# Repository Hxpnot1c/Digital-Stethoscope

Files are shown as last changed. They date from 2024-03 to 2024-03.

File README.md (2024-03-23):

# Digital-Stethoscope

## Video Presentation

Presentation video by Calday Robotics (https://www.youtube.com/watch?v=tSeS5dvHLK4)

## Video Demonstration

Demonstration video by Calday Robotics (https://www.youtube.com/watch?v=pRtG8VmfHiQ)

## Summary
<details>
    <summary>500 Word Summary</summary>
<br />
In regions where access to advanced medical equipment is limited, diagnosing cardiac irregularities such as arrhythmias, murmurs and extrasystoles poses significant challenges for healthcare providers. Our solution; a 3D printed, digital stethoscope with integrated AI. 

While analogue stethoscopes are still a vital and valued tool, it poses issues that need to be addressed. Namely, the heartbeat can be quiet, making it difficult for doctors to accurately diagnose. Moreover, they lack visual representation, which could enhance understanding.

Our device tackles these challenges with advanced sound capture. It amplifies heartbeats using a 3D printed stethoscope head, then records them with a microphone. This captured sound data is processed in real-time to create a live graph of the patient's heartbeat and rhythm. The device features a user-friendly interface that displays this live plot alongside fields for recording patient information and notes.

What sets it apart is its integration with advanced artificial intelligence, enabling discrete real-time analysis of recorded data. The integrated AI uses a deep convolutional neural network to diagnose heart irregularities such as murmurs and extrasystoles. First, the audio data is converted into features such as the zero crossing rate, a chroma short time Fourier transform, the Mel-frequency cepstrum coefficient and a Mel-Spectrogram. This allows for unnecessary information to be abstracted from the input data. The data is then fed into a deep neural network that consists of 5 layers and over 95,000 trainable parameters. This network consists of 3, 1-Dimensional convolutional layers and 2 Linear Layers. In order to train the model, we used a cross-entropy loss function and the AdamW optimiser. In order to prevent overfitting, we set the AdamW optimiser with an aggressive weight decay, upsampled minority classes and created synthetic data with added noise. This allowed it to achieve an accuracy of 98% on data that it had never seen before.

Healthcare providers will be able to receive immediate feedback and diagnostic suggestions, empowering them to make prompt and informed decisions regarding patient care.

One of the main benefits of this digital stethoscope is its low cost. With a total cost of only £40.94. Compared to traditional stethoscopes, our stethoscope presents itself as a key-choice in resource-constrained settings. In order to achieve this, we used a Raspberry Pi 3 Model B+ due to its sufficient processing power while minimising costs and an FDM 3D printer to create a majority of the stethoscope. The head and ring are made out of PLA and the connection piece for the microphone is made out of TPU to provide a sound isolating fit for the microphone. The cost allows for our design to be much more accessible in areas where medical resources are limited.

By facilitating early detection of cardiac irregularities, the Digital Stethoscope enables timely intervention and improved patient outcomes. Its accessibility extends to underserved communities, where access to specialised equipment is limited. With its potential to revolutionise cardiac diagnostics in developing countries, the Digital Stethoscope holds promise for saving lives and improving healthcare delivery worldwide.
</details>
 
## Build Guide
<details>
    <summary>Build guide</summary>
<br />
    
Print all 3D models in 'Digital-Stethoscope/3d_models':<br />
-  PLA_Stethoscope_Head.stl should be printed in PLA with 100% infil
-  PLA_Stethoscope_Ring.stl should be printed in PLA with 100% infill
-  TPU_Stethoscope_Connection.stl should be printed in TPU with 100% infill

Note: Our models were printed using a Creality CR10 Smart Pro 3D printer. Most FDM 3D printers will be sufficient.<br />

We also used the default setting on Cura slicer (with 100% infill).<br />
For Stethoscope Ring: Supports ON - Normal<br />

For the diaphragm, we used a 40mm diameter silicone piece with a thickness of 0.35mm

See Assembly Video below for a 3D rendering of how to assemble the 3D printed parts and the diaphragm.

Substitutionary Rick Roll to be replaced with assembly video (https://www.youtube.com/watch?v=KgJvibv4-vc)

All connections require no adhesive and rely on a friction fit.
In order to attach the Ring some pressure will be required, this will then provide a tight fit.

The microphone will then also provide a tight fit into the TPU connection piece

The following connections may require soldering and the use of breadboards. Please see the below pinout images to demonstrate pin connections.<br />
Connect V<sub>DD</sub> on the MCP3008 ADC to 3.3V on the Raspberry Pi using pin 17<br />
Connect V<sub>REF</sub> on the MCP3008 ADC to 3.3V on the Raspberry Pi using pin 17<br />
Connect AGND on the MCP3008 ADC to GND on the Raspberry Pi using pin 25<br />
Connect CLK on the MCP3008 ADC to GPIO 11 (SCLK) on the Raspberry Pi using pin 23<br />
Connect D<sub>OUT</sub> on the MCP3008 ADC to GPIO 9 (MISO) on the Raspberry Pi using pin 21<br />
Connect D<sub>IN</sub> on the MCP3008 ADC to GPIO 10 (MOSI) on the Raspberry Pi using pin 19<br />
Connect CS/SHDN on the MCP3008 ADC to GPIO 8 (CE0) on the Raspberry Pi using pin 8<br />
Connect GND on the MAX9814 microphone to GND on the Raspberry Pi using pin 25<br />
Connect V+ on the MAX9814 microphone to 3.3V on the Raspberry Pi using pin 17<br />
Connect OUT on the MAX9814 microphone to CH0 on the MCP3008 ADC<br />

Raspberry Pi pinout
MCP3008 ADC pinout
MAX9814 microphone pinout

The Raspberry Pi should be setup with Raspberry Pi OS (Legacy, 64 bit)<br />
Note: 64 bit is required for pytorch

Install the following dependencies using pip:<br />
-  adafruit_mcp3008
-  librosa
-  matplotlib
-  pandas
-  pyqt5
-  soundfile
-  torch

Download 'Digital-Stethoscope/src'

Run the following commands in the terminal to run the program:<br />
'sudo chrt 99 python src/model_prediction.py'
'sudo chrt 99 python src/gui.py'
'sudo chrt 99 python src/data_acquisition.py'
</details>

## Further Reading
<details>
    <summary>Definitions and useful links</summary>
<br />
Definitions:
Heart Arrhythmia:<br />
An arrhythmia is an abnormality of the heart's rhythm.

Heart Murmur:<br />
Heart murmurs are sounds — such as whooshing or swishing — made by rapid, choppy (turbulent) blood flow through the heart.

Extrasystoles/Premature ventricular contractions:<br />
Extra heartbeats that begin in one of the heart's two lower pumping chambers (ventricles).

Zero-Crossing Rate (ZCR):<br />
A measurement in audio processing that counts the number of times a signal crosses zero from positive to negative or vice versa within a specific time window. It's a simple way to characterise the "brightness" or "harshness" of a sound.
    
Chroma Short-Time Fourier Transform (Chroma STFT):<br />
A signal processing technique used to analyse audio. It breaks down the sound into its component frequencies over short periods of time. Chroma STFT focuses specifically on the pitch information, representing the signal in terms of musical notes (chroma).
    
Mel-Frequency Cepstrum Coefficient (MFCC):<br />
A feature extraction technique commonly used in speech and audio recognition. It mimics how the human auditory system perceives sound by converting the sound's frequency spectrum into a representation on the Mel scale, which approximates human hearing. MFCCs capture the spectral envelope of the sound, making them useful for tasks like speaker identification and speech recognition.
    
Mel-Spectrogram:<br />
A visual representation of a sound's frequency content over time. It uses colour to represent the intensity of different frequencies at different time points. Mel spectrograms are often used in conjunction with MFCCs, as they provide a more intuitive way to understand the spectral information captured by MFCCs.
    
Deep Neural Network (DNN):<br />
A type of artificial neural network with multiple layers of interconnected nodes. DNNs can learn complex patterns from data and are powerful tools for tasks like image recognition, natural language processing, and speech recognition.
    
Convolutional Neural Network (CNN):<br />
A powerful type of artificial neural network used to classify sounds. Similar to image processing, CNNs excel at finding patterns in audio data.
    
Trainable Parameters:<br />
The numerical values within a deep neural network that are adjusted during the training process. These parameters determine how the network maps input data to output predictions. By adjusting these parameters, the network learns to perform a specific task.
    
1-Dimensional Convolutional Layers:<br />
A specific type of layer in a deep neural network used for processing sequential data like audio or text. These layers apply a filter (like a small window) that slides across the input data, extracting features based on local patterns. By stacking multiple convolutional layers, the network can learn increasingly complex features.
    
Linear Layers:<br />
Layers in a deep neural network that perform a weighted sum of their inputs. These layers are often used at the end of a network to combine the learned features and produce the final output prediction.
    
ReLU Activation Function:<br />
A popular activation function used in artificial neural networks. It adds a non-linearity to the network, which is crucial for its ability to learn complex patterns from data.
    
Cross-Entropy Loss Function:<br />
A common function used to measure the error between a neural network's predictions and the true labels of the data. It's particularly useful for classification tasks where the network outputs probabilities for different categories. The loss function helps the network learn by indicating how much its predictions deviate from the desired outcome.
    
AdamW Optimizer:<br />
An optimization algorithm used to train deep neural networks. It efficiently adjusts the network's trainable parameters based on the calculated loss function. AdamW is a variant of the Adam optimizer that addresses certain stability issues.
    
Overfitting:<br />
A situation where a deep neural network performs well on the training data but poorly on unseen data. This occurs when the network memorises specific details of the training examples rather than learning generalisable patterns. Weight decay and other regularisation techniques can help prevent overfitting.
    
Weight Decay:<br />
A technique used during training to prevent a deep neural network from overfitting to the training data. It penalises the network for having large weights, encouraging it to learn more generalisable features.
    
Dropout Layers:<br />
A technique used in artificial neural networks to improve their performance, especially to address overfitting, by randomly deactivating a certain percentage of neurons in a layer during training. This forces the network to learn to use different combinations of neurons each time, preventing it from relying too heavily on any specific neuron or connection.
    
Upsampling:<br />
An operation that increases the resolution of an image or signal. In audio processing, it might involve interpolating new data points between existing ones to create a higher sampling rate.
    
Minority Classes:<br />
In a classification task with multiple categories, the classes with the fewest data points are referred to as minority classes.
    
Class Imbalance:<br />
A situation in a classification dataset where some classes have significantly fewer data points than others. This can pose challenges for training a deep neural network, as the model might prioritise learning patterns from the majority classes and perform poorly on the minority classes.
    
Noise (in reference to audio):<br />
Unwanted sound that disrupts the desired audio signal. Noise can come from various sources and can significantly impact the quality and clarity of audio recordings or playback.
    
MAX9814:<br />
An integrated circuit (IC) that combines a microphone amplifier with automatic gain control (AGC). It's commonly used in audio applications to boost weak microphone signals to a usable level. AGC helps ensure the amplified signal stays within a certain range, preventing distortion.
    
MCP3008:<br />
An analogue-to-digital converter (ADC) IC that converts analogue voltage signals from sensors or other circuits into digital data that can be processed by microcontrollers or computers. It has 8 channels, meaning it can convert signals from up to 8 analogue inputs simultaneously. The MCP3008 typically uses a serial communication protocol (SPI) to communicate with the microcontroller.

Links to helpful videos:
But what is a neural network? | Chapter 1, Deep learning by 3Blue1Brown<br />
But what is a convolution? by 3Blue1Brown<br />
But what is the Fourier Transform?  A visual introduction. by 3Blue1Brown<br />

</details>

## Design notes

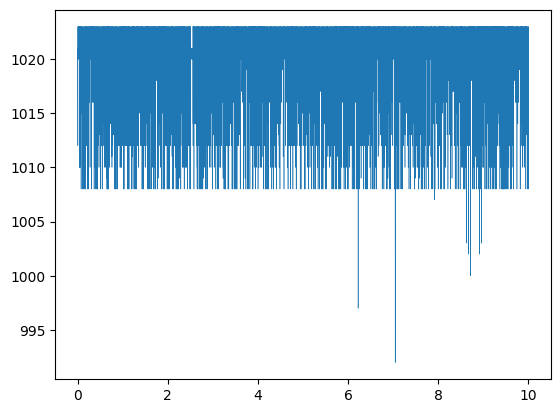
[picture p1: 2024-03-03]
Res/ADC_Readings.png

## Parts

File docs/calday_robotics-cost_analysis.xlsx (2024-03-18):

 | Name | Commercial Cost | Links
Raspberry Pi | 3 Model B+ | £39.34 | https://www.rapidonline.com/raspberry-pi-3-model-b-1-quad-core-1-4ghz-1gb-ram-wifi-bluetooth-75-1005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
PLA | Geeetech 10kg | £0.26 | https://www.aliexpress.com/item/1005006593506584.html
TPU | OVERTURE TPU Filament (1kg Spools) | £0.04 | https://www.amazon.co.uk/OVERTURE-Filament-Flexible-Consumables-Dimensional/dp/B09QLT436P
Mic | MAX9418 | £0.40 | https://www.aliexpress.com/item/1005006371216670.html
Diaphram | Jan-huei K.H. Industry Co | £0.19 | Quote from Jan-huei K.H. Industry Co., Ltd.
Wires | 2m with insulation | £0.15 | https://www.aliexpress.com/item/1005006537337468.html
ADC | MCP3008 | £0.38 | https://www.aliexpress.com/item/1005005944889779.html
Breadboard | 170 Tie Point Solderless PCB | £0.18 | https://pl.aliexpress.com/item/1005006590495350.html
Total (excluding RPi) |  | £1.60
Total |  | £40.94
 |  |  |  | $0.24 = £0.19

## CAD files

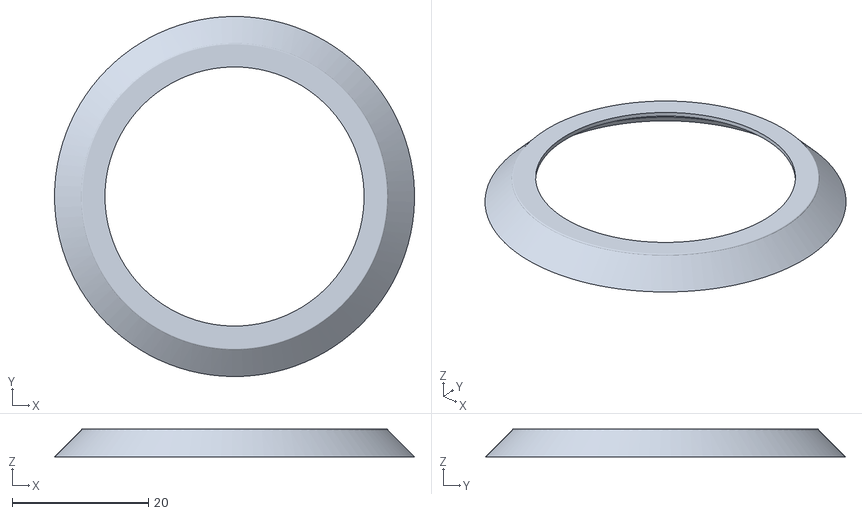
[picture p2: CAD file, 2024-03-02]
3d_models/PLA_Stethoscope_Ring.stl
52.8 x 52.8 x 4.10

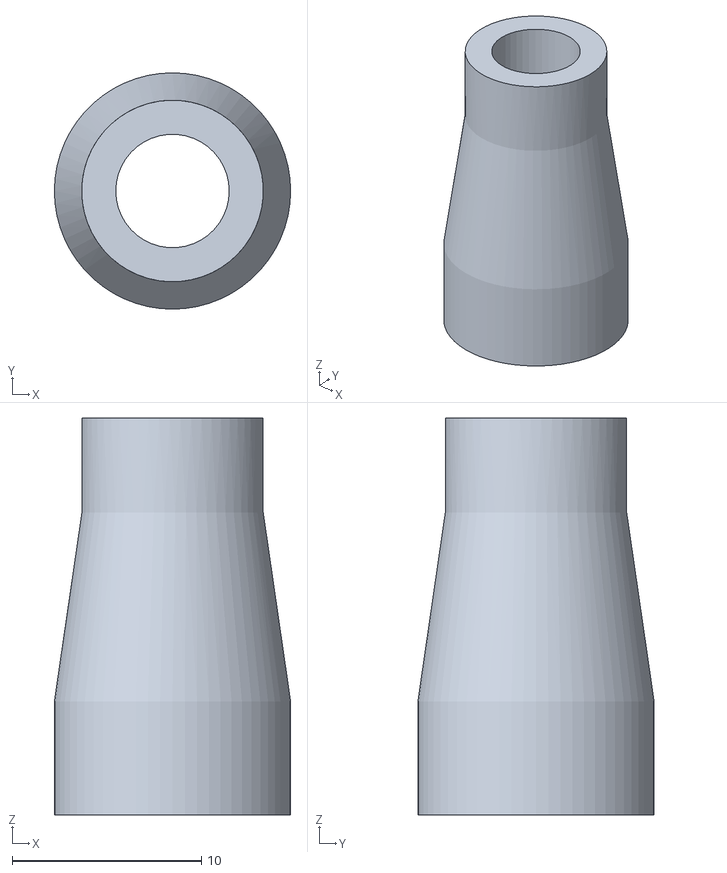
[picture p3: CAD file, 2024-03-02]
3d_models/TPU_Stethoscope_Connection.stl
12.5 x 12.5 x 21.0

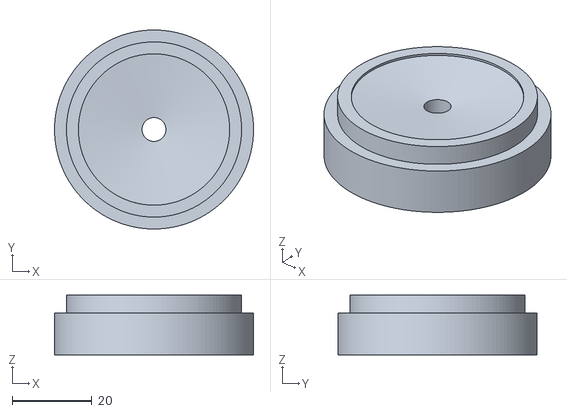
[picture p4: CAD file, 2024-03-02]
3d_models/PLA_Stethoscope_Head.stl
50.0 x 50.0 x 15.0

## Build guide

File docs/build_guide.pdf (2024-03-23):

# Build Guide

Link to GitHub - https://github.com/Hxpnot1c/Digital-Stethoscope

Print all 3D models in 'Digital-Stethoscope/3d_models':

- PLA_Stethoscope_Head.stl should be printed in PLA with 100% infill
- PLA_Stethoscope_Ring.stl should be printed in PLA with 100% infill
- TPU_Stethoscope_Connection.stl should be printed in TPU with 100% infill

Note: Our models were printed using a Creality CR10 Smart Pro 3D printer. Most FDM 3D printers will be sufficient.

We also used the default setting on Cura slicer (with 100% infill).
For Stethoscope Ring: Supports ON - Normal

For the diaphragm, we used a 40mm diameter silicone piece with a thickness of 0.35mm

See Assembly Video (https://www.youtube.com/watch?v=KgJvibv4-vc) below for a 3D rendering of how to assemble the 3D printed parts and the diaphragm.

All connections require no adhesive and rely on a friction fit. In order to attach the Ring some pressure will be required, this will then provide a tight fit.

The microphone will then also provide a tight fit into the TPU connection piece

The following connections may require soldering and the use of breadboards. Please see the below pinout images to demonstrate pin connections.
Connect VDD on the MCP3008 ADC to 3.3V on the Raspberry Pi using pin 17
Connect VREF on the MCP3008 ADC to 3.3V on the Raspberry Pi using pin 17
Connect AGND on the MCP3008 ADC to GND on the Raspberry Pi using pin 25 Connect CLK on the MCP3008 ADC to GPIO 11 (SCLK) on the Raspberry Pi using pin 23 Connect DOUT on the MCP3008 ADC to GPIO 9 (MISO) on the Raspberry Pi using pin 21 Connect DIN on the MCP3008 ADC to GPIO 10 (MOSI) on the Raspberry Pi using pin 19 Connect CS/SHDN on the MCP3008 ADC to GPIO 8 (CE0) on the Raspberry Pi using pin 8 Connect GND on the MAX9814 microphone to GND on the Raspberry Pi using pin 25 Connect V+ on the MAX9814 microphone to 3.3V on the Raspberry Pi using pin 17 Connect OUT on the MAX9814 microphone to CH0 on the MCP3008 ADC

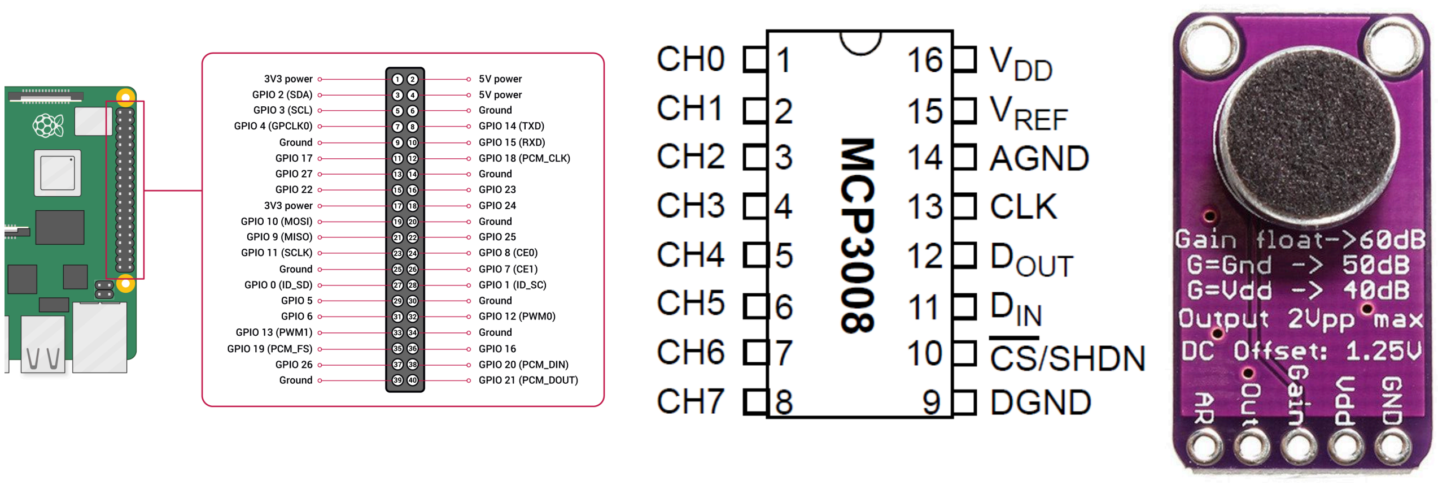
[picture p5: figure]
Note: 64 bit is required for pytorch

The Raspberry Pi should be setup with Raspberry Pi OS (Legacy, 64 bit)

Install the following dependencies using pip:

- adafruit_mcp3008
- librosa
- matplotlib
- pandas
- pyqt5
- sound file
- torch

Download 'Digital-Stethoscope/src'

Run the following commands in the terminal to run the program:

- 'sudo chrt 99 python src/model_prediction.py'
- 'sudo chrt 99 python src/gui.py'
- 'sudo chrt 99 python src/data_acquisition.py'

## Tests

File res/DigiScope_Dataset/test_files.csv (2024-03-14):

unlabelled_test/101_1305030823364_A.wav
unlabelled_test/101_1305030823364_D.wav
unlabelled_test/101_1305030823364_F.wav
unlabelled_test/103_1305031931979_A.wav
unlabelled_test/103_1305031931979_C.wav
unlabelled_test/105_1305033453095_B.wav
unlabelled_test/105_1305033453095_D.wav
unlabelled_test/106_1306776721273_B.wav
unlabelled_test/106_1306776721273_D.wav
unlabelled_test/107_1305654946865_B.wav
unlabelled_test/107_1305654946865_D.wav
unlabelled_test/108_1305654420093_C.wav
unlabelled_test/109_1305653646620_B.wav
unlabelled_test/109_1305653646620_D.wav
unlabelled_test/109_1305653972028_B.wav
unlabelled_test/109_1305653972028_D.wav
unlabelled_test/110_1305655332337_D.wav
unlabelled_test/112_1306243000964_C.wav
unlabelled_test/113_1306244002866_C.wav
unlabelled_test/115_1306259437619_D.wav
unlabelled_test/116_1306258689913_B.wav
unlabelled_test/117_1306262456650_B1.wav
unlabelled_test/118_1306262335509_A.wav
unlabelled_test/118_1306262335509_A1.wav
unlabelled_test/118_1306262335509_C2.wav
unlabelled_test/121_1306263877235_B.wav
unlabelled_test/122_1306325762831_A.wav
unlabelled_test/122_1306325762831_B.wav
unlabelled_test/123_1306331925797_A.wav
unlabelled_test/123_1306331925797_D.wav
unlabelled_test/125_1306332456645_B2.wav
unlabelled_test/126_1306777102824_C1.wav
unlabelled_test/126_1306777102824_D1.wav
unlabelled_test/127_1306764300147_D.wav
unlabelled_test/128_1306344005749_C.wav
unlabelled_test/129_1306344506305_B.wav
unlabelled_test/130_1306347376079_A.wav
unlabelled_test/132_1306758754432_A.wav
unlabelled_test/132_1306758754432_B.wav
unlabelled_test/132_1306758754432_D.wav
unlabelled_test/134_1306428161797_A.wav
unlabelled_test/134_1306428161797_B.wav
unlabelled_test/135_1306428972976_D.wav
unlabelled_test/136_1306429977501_A.wav
unlabelled_test/136_1306429977501_D.wav
unlabelled_test/137_1306764999211_A.wav
unlabelled_test/137_1306764999211_B1.wav
unlabelled_test/137_1306764999211_D2.wav
unlabelled_test/138_1306762146980_C.wav
unlabelled_test/139_1306519274653_B.wav
unlabelled_test/139_1306519274653_C.wav
unlabelled_test/141_1306520154450_A.wav
unlabelled_test/141_1306520154450_D.wav
unlabelled_test/142_1306763049574_C.wav
unlabelled_test/143_1306763822290_D.wav
unlabelled_test/144_1306522408528_A.wav
unlabelled_test/145_1307987561278_A.wav
unlabelled_test/145_1307987561278_D.wav
unlabelled_test/146_1306778707532_C.wav
unlabelled_test/146_1306778707532_D31.wav
unlabelled_test/147_1306523973811_D.wav
unlabelled_test/148_1306768801551_A.wav
unlabelled_test/148_1306768801551_C.wav
unlabelled_test/148_1306768801551_D.wav
unlabelled_test/149_1306776016110_C.wav
unlabelled_test/150_1306776340746_D.wav
unlabelled_test/151_1306779785624_A1.wav
unlabelled_test/152_1306779561195_B.wav
unlabelled_test/152_1306779561195_C.wav
unlabelled_test/152_1306779561195_D1.wav
unlabelled_test/153_1306848820671_D.wav
unlabelled_test/154_1306935608852_A.wav
unlabelled_test/154_1306935608852_A2.wav
unlabelled_test/154_1306935608852_D.wav
unlabelled_test/154_1306935608852_D1.wav
unlabelled_test/155_1306935902813_B.wav
unlabelled_test/155_1306935902813_B2.wav
unlabelled_test/155_1306935902813_D.wav
unlabelled_test/156_1306936373241_C.wav
unlabelled_test/156_1306936373241_D.wav
unlabelled_test/157_1306937583792_C.wav
unlabelled_test/159_1307018640315_A.wav
unlabelled_test/159_1307018640315_B.wav
unlabelled_test/159_1307018640315_C.wav
unlabelled_test/160_1307100683334_C.wav
unlabelled_test/161_1307101199321_D.wav
unlabelled_test/162_1307101835989_C.wav
unlabelled_test/163_1307104470471_B.wav
unlabelled_test/163_1307104470471_B1.wav
unlabelled_test/163_1307104470471_D.wav
unlabelled_test/164_1307106095995_D.wav
unlabelled_test/165_1307109069581_B.wav
unlabelled_test/167_1307111318050_C1.wav
unlabelled_test/167_1307111318050_D.wav
unlabelled_test/169_1307970398039_B.wav
unlabelled_test/169_1307970398039_C1.wav
unlabelled_test/170_1307970562729_D.wav
unlabelled_test/171_1307971016233_C.wav
unlabelled_test/171_1307971016233_F.wav
unlabelled_test/172_1307971284351_C.wav
unlabelled_test/172_1307971284351_D.wav
unlabelled_test/173_1307973611151_D.wav
unlabelled_test/174_1307987737137_C.wav
unlabelled_test/175_1307987962616_C.wav
unlabelled_test/176_1307988171173_A1.wav
unlabelled_test/176_1307988171173_C.wav
unlabelled_test/176_1307988171173_C1.wav
unlabelled_test/177_1307989650056_C.wav
unlabelled_test/178_1307989887769_A.wav
unlabelled_test/179_1307990076841_D1.wav
unlabelled_test/180_1307990956284_B.wav
unlabelled_test/180_1307990956284_D.wav
unlabelled_test/181_1308052613891_C.wav
unlabelled_test/184_1308073010307_C.wav
unlabelled_test/186_1308073648738_C.wav
unlabelled_test/186_1308073648738_D1.wav
unlabelled_test/187_1308073994223_C.wav
unlabelled_test/189_1308075231945_A.wav
unlabelled_test/189_1308075231945_C.wav
unlabelled_test/191_1308077299430_C.wav
unlabelled_test/191_1308077299430_D.wav
unlabelled_test/193_1308078104592_A.wav
unlabelled_test/193_1308078104592_D.wav
unlabelled_test/194_1308139824187_C.wav
unlabelled_test/195_1308140095331_D.wav
unlabelled_test/196_1308141034858_D.wav
unlabelled_test/197_1308141235553_B.wav
unlabelled_test/200_1308144251434_C1.wav
unlabelled_test/201_1308144942432_B.wav
unlabelled_test/202_1308145175747_B.wav
unlabelled_test/203_1308162026258_C.wav
unlabelled_test/204_1308159229275_B1.wav
unlabelled_test/206_1308159601959_C1.wav
unlabelled_test/207_1308159792607_B3.wav
unlabelled_test/209_1308162216750_B.wav
unlabelled_test/209_1308162216750_C.wav
unlabelled_test/210_1308162935880_D.wav
unlabelled_test/212_1308245076477_C.wav
unlabelled_test/213_1308245263936_B.wav
unlabelled_test/214_1308245489717_A1.wav
unlabelled_test/215_1308245664733_D.wav
unlabelled_test/216_1308245839516_B1.wav
unlabelled_test/217_1308246111629_A.wav
unlabelled_test/217_1308246111629_B.wav
unlabelled_test/217_1308246111629_D.wav
unlabelled_test/220_1308250132896_A.wav
unlabelled_test/222_1308336218979_B.wav
unlabelled_test/227_1308594233667_D.wav
unlabelled_test/229_1308594979317_C.wav
unlabelled_test/231_1308748318393_B.wav
unlabelled_test/231_1308748318393_C.wav
unlabelled_test/232_1308748524018_A1.wav
unlabelled_test/232_1308748524018_D.wav
unlabelled_test/235_1308749032454_C1.wav
unlabelled_test/235_1308749032454_D1.wav
unlabelled_test/237_1308750231222_C1.wav
unlabelled_test/239_1309195730333_D.wav
unlabelled_test/240_1309196119795_D.wav
unlabelled_test/242_1309197394064_A.wav
unlabelled_test/242_1309197394064_C.wav
unlabelled_test/243_1309197760898_D.wav
unlabelled_test/245_1309198844065_A.wav
unlabelled_test/245_1309200438094_C.wav
unlabelled_test/248_1309201683806_B.wav
unlabelled_test/248_1309201683806_D.wav
unlabelled_test/254_1309350589009_B.wav
unlabelled_test/255_1309351210897_B.wav
unlabelled_test/259_1309352630271_B.wav
unlabelled_test/260_1309353164458_A.wav
unlabelled_test/262_1309355283807_B.wav
unlabelled_test/264_1309356143724_A.wav
unlabelled_test/268_1309368960960_A.wav
unlabelled_test/268_1309368960960_E.wav
unlabelled_test/270_1309369533040_D.wav
unlabelled_test/271_1309369876160_B.wav
unlabelled_test/272_1309370164386_B.wav
unlabelled_test/274_1311075637574_C.wav
unlabelled_test/278_1311163365896_C.wav
unlabelled_test/278_1311163365896_D.wav
unlabelled_test/280_1311165195344_B.wav
unlabelled_test/281_1311165683454_C.wav
unlabelled_test/282_1311166081161_D.wav
unlabelled_test/284_1311168471850_C.wav
unlabelled_test/286_1311170606028_B.wav
unlabelled_test/287_1311170903290_D.wav
unlabelled_test/288_1311164615284_B.wav
unlabelled_test/290_1311182875320_B.wav
unlabelled_test/293_1311680805936_B.wav
unlabelled_test/293_1311680805936_B2.wav
unlabelled_test/294_1311681084248_D.wav
unlabelled_test/296_1311682952647_A.wav
unlabelled_test/296_1311682952647_B.wav
unlabelled_test/300_1311772096120_B.wav
unlabelled_test/300_1311772096120_C.wav
unlabelled_test/300_1311772096120_D.wav

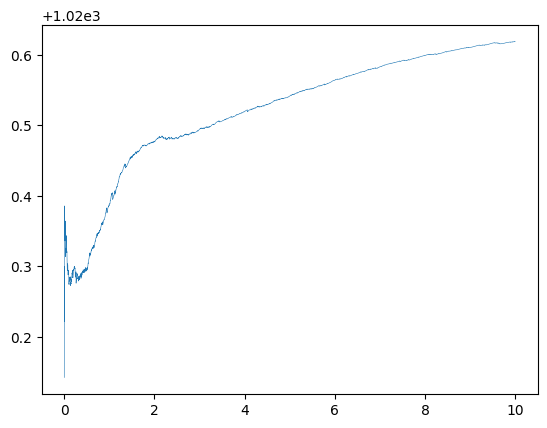
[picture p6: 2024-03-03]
Res/Data_Test.png

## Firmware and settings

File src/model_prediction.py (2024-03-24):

import numpy as np
import librosa
import pathlib
import torch
from time import sleep
import pandas as pd
from model import ConvolutionalNN


ROOT_DIR = pathlib.Path(__file__).resolve().parent


# Writes to inference.csv with diagnosis and confidence of -1 to show the AI is collecting/processing data
df = pd.DataFrame([[-1, -1]])
df.to_csv(ROOT_DIR / 'inference.csv', index=False)


# Ensures model is loaded to cpu as Raspberry Pi is not capable of using CUDA
DEVICE = torch.device('cpu')
model = ConvolutionalNN().to(DEVICE)
model.load_state_dict(torch.load(ROOT_DIR / 'model.pth', map_location=DEVICE))


model.eval() # Loads model in evaluation mode


def gen_features():
    # Generates features such as zero crossing rate, chroma stft, mfcc, rms and mel spectrogram from audio data
    SAMPLE_RATE = 10000
    original_data, sr = librosa.load(ROOT_DIR / 'audio_data.wav', sr=1000, offset=0)
    data = librosa.resample(original_data, orig_sr=sr, target_sr=SAMPLE_RATE)

    mean_zero_crossing_rate = np.mean(librosa.feature.zero_crossing_rate(y=data).T, axis=0)
    mean_zero_crossing_rate = np.pad(mean_zero_crossing_rate, (64, 63))
    features = np.array(mean_zero_crossing_rate)

    stft_data = np.abs(librosa.stft(data))
    chroma_mean = np.mean(librosa.feature.chroma_stft(S=stft_data, sr=SAMPLE_RATE).T, axis=0)
    chroma_mean = np.pad(chroma_mean, (58, 58))
    features = np.vstack((features, chroma_mean))

    mfcc_data = np.mean(librosa.feature.mfcc(y=data, sr=SAMPLE_RATE).T, axis=0)
    mfcc_data = np.pad(mfcc_data, (54, 54))
    features = np.vstack((features, mfcc_data))
    
    rms_data = np.mean(librosa.feature.rms(y=data).T, axis=0)
    rms_data = np.pad(rms_data, (64, 63))
    features = np.vstack((features, rms_data))

    mel_data = np.mean(librosa.feature.melspectrogram(y=data, sr=SAMPLE_RATE).T, axis=0)
    features = np.vstack((features, mel_data))

    return features


def one_hot_encode(label):
        # One hot encodes label data to use to train the model
        encoded_labels = [0, 0, 0]
        encoded_labels[label] = 1
        return torch.tensor(encoded_labels, device=DEVICE)


input = torch.tensor(gen_features(), device=DEVICE).unsqueeze(0) # Generates input data features

loss_fucntion = torch.nn.CrossEntropyLoss() # Defines loss function to use for confidence calculation

while True:
    # Check audio_data.wav for updates every 2 seconds and make prediction based on new data if audio_data.wav has changed
    sleep(2)
    if not torch.all(input.eq(new_data := torch.tensor(gen_features(), device=DEVICE).unsqueeze(0))):
        input = new_data
        output = model(input.float())

        _, prediction = torch.max(output, 1)
        prediction = int(prediction)

        confidence = 1-abs(loss_fucntion(output.float(), one_hot_encode(prediction).unsqueeze(0).float()).item())

        print(f'Diagnosis: {prediction}\nConfidence: {confidence*100:.1f}')

        # Write prediction and confidence to inference.csv to be read by the GUI script
        df = pd.DataFrame([[prediction, confidence]])
        df.to_csv(ROOT_DIR / 'inference.csv', index=False)

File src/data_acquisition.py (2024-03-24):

from Adafruit_MCP3008 import MCP3008
from Adafruit_GPIO.SPI import SpiDev
import numpy as np
import time
import pandas as pd
import pathlib
from soundfile import write


ROOT_DIR = pathlib.Path(__file__).resolve().parent


# Access ADC using hardware SPI (because its faster)
SPI_PORT = 0
SPI_DEVICE = 0
mcp = MCP3008(spi=SpiDev(SPI_PORT, SPI_DEVICE))


# Returns mean value of an array
def mean(values):
    if not len(values):
        return mcp.read_adc(0)
    sum = np.sum(values)
    mean = sum / len(values)
    return mean


# Rescales values from one range to another
def remap_range(values, org_min, org_max, new_min, new_max):
    org_range = org_max - org_min
    new_range = new_max - new_min
    normalised_values = (values - org_min) / org_range
    remapped_values = (normalised_values * new_range) + new_min
    return remapped_values


# Cycles time period readings forward one time for live BPM calculation
def cycle_forward(new_val, t1, t2, t3, t4, t5):
    t5 = t4
    t4 = t3
    t3 = t2
    t2 = t1
    t1 = new_val
    return t1, t2, t3, t4, t5


# Calculates heart rate in beats per minute given last 5 time periods between full beats
def calculate_heart_rate(t1, t2, t3, t4, t5):
    # Determines beats per second
    # Recent readings are weighted more than older readings by the following formula: weight for tₙ = f(n) where f(n) = round(5/sqrt(6) * sqrt(-n+6))
    # Therefore bps = sum(f(n) / tₙ)) / sum(f(n))
    bps = (5/t1 + 4/t2 + 4/t3 + 3/t4 + 2/t5) / 18
    # Converts to beats per minute
    bpm = bps * 60
    return bpm


# Initialise variables
values, binned_values, bpm_sample_times, bpm_values = [], [], [], []
SAMPLING_RATE = 1000 # Sampling rate of 1000 to align with preferred Nyquist frequency of 500Hz
SAMPLE_PERIOD = 1 / SAMPLING_RATE
SAMPLING_TIME = 180 # Samples for 3 minutes before automatically stopping
bpm_sample_num = 11 + 2
next_bpm_sample_time = 0

print('Sampling...')
STARTTIME = time.perf_counter()

# Main loop to collect heart data and use equal width binning to go from a variable sampling rate to a sampling rate of 1000
# Iterates through bins
for bin in range(1, SAMPLING_TIME * SAMPLING_RATE + 1):
    t_end = STARTTIME + (bin * SAMPLE_PERIOD) # Time to sample upto for current bin

    # Samples for 1ms and saves data to values
    while (time.perf_counter()) < t_end:
        values.append(mcp.read_adc(0))

    # Computes mean of data from 1ms of sampling and appends it binned_values
    binned_values.append(mean_val := mean(values))
    values = [] # Empties values for the next iteration/bin


    # Calculates realtive current bin time
    current_time = SAMPLE_PERIOD * bin - (SAMPLE_PERIOD * 0.5)

    # Record beat if amplitude is greater than or equal to 700 and enough time has passed since the last recorded beat
    if mean_val >= 700 and current_time >= next_bpm_sample_time:
        bpm_sample_times.append(current_time)
        next_bpm_sample_time = current_time + 0.2

        # Initialise time period variables
        if len(bpm_sample_times) == 11:
            t1 = bpm_sample_times[-1] - bpm_sample_times[-3]
            t2 = bpm_sample_times[-3] - bpm_sample_times[-5]
            t3 = bpm_sample_times[-5] - bpm_sample_times[-7]
            t4 = bpm_sample_times[-7] - bpm_sample_times[-9]
            t5 = bpm_sample_times[-9] - bpm_sample_times[-11]
            # Append BPM vlaue to bpm_values
            bpm_values.append(calculate_heart_rate(t1, t2, t3, t4, t5))

        # Every 2 values (one full double beat) update the time period variables and append the updates BPM to bpm_values
        elif len(bpm_sample_times) == bpm_sample_num:
            bpm_sample_num += 2
            t1, t2, t3, t4, t5 = cycle_forward(bpm_sample_times[-1] - bpm_sample_times[-3], t1, t2, t3, t4, t5)
            bpm_values.append(calculate_heart_rate(t1, t2, t3, t4, t5)) 

    # Every 800ms calculate values to plot on GUI
    if (bin+1) % 800 == 0:
        newest_bins = binned_values[-800:] # Only take newest 800 binned values
        rebinned_values = [] 

        # Split values into 400 new equal width bins to display on GUI at a rate of 500Hz
        for index in range(400):
            rebinned_values.append(sum(newest_bins[index*2:(index+1)*2]) / 2)

        # Update data.csv with new 500 samples per second heart data and most recent BPM (if BPM hasn't been calculated yet, output BPM of 0)
        if len(bpm_values) == 0:
            rebinned_values.append(0)
            pd.Series(rebinned_values).to_csv(ROOT_DIR / 'data.csv')
        else:
            bpm = round(bpm_values[-1])
            rebinned_values.append(bpm)
            pd.Series(rebinned_values).to_csv(ROOT_DIR / 'data.csv', index=False)

    # Every 10 seconds save heart data to audio_data.wav
    if (bin+1) % 10000 == 0:
        # Rescale data to be in required range to save as .wav
        data = remap_range(np.array(binned_values), 0, 1024, -1, 1)
        
        write(file=ROOT_DIR / 'audio_data.wav', data=data, samplerate=SAMPLING_RATE)

        # Reset binned_values
        binned_values = []

print('Sampling complete!')

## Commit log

2024-03-02 ADC testing script
2024-03-02 Added 3D models for stethoscope head, ring and tube connection to microphone
    [PLA Stethoscope Head.stl, PLA Stethoscope Ring.stl, TPU Stethoscope Connection.stl]
2024-03-02 Rename PLA Stethoscope Head.stl to PLA_Stethoscope_Head.stl
    [PLA_Stethoscope_Head.stl]
2024-03-02 Rename PLA Stethoscope Ring.stl to PLA_Stethoscope_Ring.stl
    [PLA_Stethoscope_Ring.stl]
2024-03-02 Rename TPU Stethoscope Connection.stl to TPU_Stethoscope_Connection.stl
    [TPU_Stethoscope_Connection.stl]
2024-03-03 adjusted sampling rate and added average samples per second output
2024-03-03 Data plot from Digital-Stethoscope/Testing/Data_Collection.py with ADC connected to potentiometer at full
2024-03-03 Testing with audio filtering
2024-03-07 After exercise high bpm tests with different sample rates
2024-03-11 New data readings with longer wires (does not seem to affect signal quality)
2024-03-13 Added cleaned dataset from The Pascal Classifying Heart Sounds Challenge 2011 (CHSC2011)
    [labels.csv, labels_composition.csv]
2024-03-14 Cleaned and modified csv data
    [labels.csv, labels_composition.csv, test_files.csv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]
2024-03-17 Moved to PyQt5 and fixed white bar at bottom of screen issue
    [gui.py]
2024-03-18 Renamed directories
    [PLA_Stethoscope_Head.stl, PLA_Stethoscope_Ring.stl, TPU_Stethoscope_Connection.stl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]
2024-03-18 Renamed files
    [cost_analysis.xlsx]
2024-03-18 Revert "Renamed files"
    This reverts commit f9d3ce50bfb6ac3491275eba6a21ba96bde3425e.
    [cost_analysis.xlsx]
2024-03-18 Revert "Delete Res directory (renamed)"
    new file: Res/Archived_Data/Audio/Filtered_Signal.wav
    new file: Res/Archived_Data/Audio/Input_Signal.wav
    new file: Res/Archived_Data/Audio/Raw_Signal.wav
    new file: Res/Archived_Data/Image Plots/Potentiometer on Full/ADC_Readings.png
    new file: Res/Archived_Data/Image Plots/Potentiometer on Full/Data_Test.png
    new file: Res/Archived_Data/Image Plots/Stethoscope Head Attached/Data_Collection_Comparison.png
    new file: Res/Archived_Data/Image Plots/Stethoscope Head Attached/Data_Test (4 double taps on diaphragm using finger).png
    new file: Res/Archived_Data/Image Plots/Stethoscope Head Attached/Data_Test (Ambient).png
    new file: Res/A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
    [test_files.csv, train_data.csv, training_labels.csv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]
2024-03-18 Renaming directory
    [test_files.csv, train_data.csv, training_labels.csv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]
2024-03-18 Renamed directory
    [test_files.csv, train_data.csv, training_labels.csv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]
2024-03-19 GUI and data sampling integration
    [data.csv]
2024-03-23 Updated data_preprocessor.py and created data_upsampler.py to upsample minority classes to prevent class imbalance
    [data_preprocessor.py, data_upsampler.py]
2024-03-23 Renamed DigiScope Dataset to DigiScope_Dataset, added synthetic data to prevent class imablance and added data from our stethoscope to improve compatibility with our data
    [test_files.csv, train_data.csv, training_labels.csv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]
2024-03-23 Source code for final build
    [inference.csv]
2024-03-23 Polishing repo
    [test_files.csv, train_data.csv, training_labels.csv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]
2024-03-23 Rename Assembly Video.avi to assembly_video.avi
2024-03-23 Rename Calday Robotics - Cost Analysis.xlsx to calday_robotics-cost_analysis.xlsx
    [calday_robotics-cost_analysis.xlsx]
2024-03-23 Fixed inference.csv save path issue
    [model_prediction.py]
2024-03-23 Moved documentation to /docs and added Calday Robotics logo
    [calday_robotics-cost_analysis.xlsx]
2024-04-17 Error from misinput when adding comments
    [gui.py]
2024-04-29 Fixed BPM alignment
    [data.csv]
